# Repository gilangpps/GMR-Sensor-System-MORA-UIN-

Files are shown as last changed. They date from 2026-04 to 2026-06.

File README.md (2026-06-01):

# GMR Sensor System [MORA-UIN]

Real-time Giant Magnetoresistance sensor system for calibrated magnetic field measurement. Two kit variants, Python GUIs, MQTT IoT interface, and machine learning pipelines — built with Arduino + ADS1115.

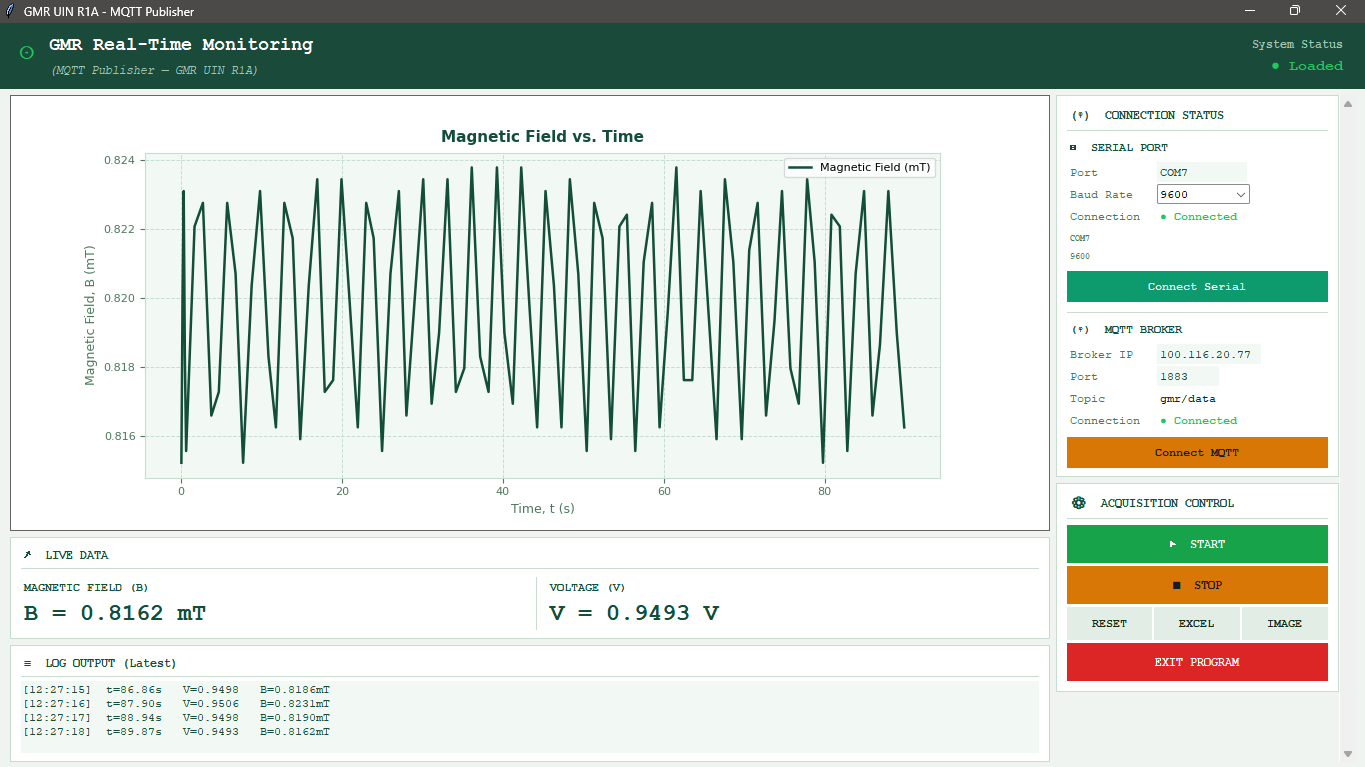
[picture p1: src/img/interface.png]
Interface Preview


---

## Hardware Variants

| Variant | Series | Color | Developed At |
|---|---|---|---|
| **GMR-UIN-R1A** | 1A | Blue | CV. Bolabot Techno Robotic Institute |
| **GMR-UIN-R1B** | 1B | Yellow | Lab. Fisika Material, UIN Bandung |

Identical in circuitry and firmware; differs only in series designation and enclosure color.

---

## Repository Structure

```
.
├── main.ino                         # Arduino firmware (ADS1115 reader)
├── magnetic_field_calibration.py    # Calibration script
├── output-template.xlsx             # Excel calibration template
│
├── GMR-UIN-R1A/                     # Blue kit
│   ├── GMR-UIN-R1A-Data-Acquisition.py
│   ├── src/                         # Calibration data, graphs
│   │   ├── r1a_calibration_report.xlsx
│   │   ├── r1a_calibration-graph.png
│   │   ├── r1a_regression-plot.png
│   │   ├── raw-data/                # (15 xlsx files, 1V–15V)
│   │   └── raw-b-data/              # (15 xlsx files, 1V–15V)
│   └── MQTT-interface/
│       ├── README.md
│       ├── 1.0.0/                   # Initial publisher & subscriber
│       ├── 1.0.0.f/                 # Feature-update patch
│       └── 1.1.0/                   # Latest patch
│
├── GMR-UIN-R1B/                     # Yellow kit
│   ├── GMR-UIN-R1B-Data-Acquisition.py
│   ├── src/
│   │   ├── r1b_calibration.png
│   │   ├── r1b_regression-plot.png
│   │   ├── r1b-calibration_report.xlsx
│   │   ├── raw_data/V_Helmholtz/    # (14 xlsx, 3V–16V)
│   │   └── raw-b-data/              # (13 xlsx, 3V–15V)
│   └── MQTT-interface/
│       ├── README.md
│       └── 1.1.0/                   # Publisher & subscriber
│
├── src/
│   ├── img/interface.png
│   ├── GMR-mechatronics.jpg
│   ├── manual-book-GMR-UIN-MORA.pdf
│   ├── schematic/                   # Schematics, PCB layout
│   └── docs/                        # Technical documentation
│
└── misc/
    ├── gui-prototype/               # 0.1.0 and 0.1.1 interface drafts
    └── machine-learning/
        ├── GMR_RF_glucose_monohydrate/          # RF regression (no GOx)
        ├── GMR_RF_GOx_Glucose Monohydrate/      # RF regression (with GOx)
        └── GMR_SVR-KNN-RF-Fe3O4/                # SVR / KNN / RF / LR models
```

---

## Quick Start

### 1. Arduino Firmware

Upload `main.ino` to your board. It reads the GMR sensor via ADS1115 (I²C) and outputs voltage over serial at 9600 baud.

### 2. Data Acquisition GUI

Pick your kit and run:

```bash
python GMR-UIN-R1A/GMR-UIN-R1A-Data-Acquisition.py   # Blue kit
python GMR-UIN-R1B/GMR-UIN-R1B-Data-Acquisition.py   # Yellow kit
```

### 3. Calibration

```bash
python magnetic_field_calibration.py
```

---

## MQTT Interface

Both kits support MQTT-based remote monitoring via publisher/subscriber modules. Multiple patch versions exist under each kit's `MQTT-interface/` directory. For Mosquitto broker setup and full documentation, refer to the respective `MQTT-interface/README.md`.

| Kit | Versions |
|-----|---|
| R1A | `1.0.0`, `1.0.0.f`, `1.1.0` |
| R1B | `1.1.0` |

---

## Machine Learning

Pre-trained models for Fe₃O₄ classification/regression and glucose concentration prediction (with/without GOx enzyme) are available under `misc/machine-learning/`.

---

## Environment Setup

**Dependencies:** `pyserial`, `matplotlib`, `pandas`, `openpyxl`, `paho-mqtt`

```bash
pip install pyserial matplotlib pandas openpyxl paho-mqtt
```

Adjust the serial port in the acquisition script (`COM3` / `/dev/ttyUSB0`) to match your system.

---

## Acknowledgements

Funded by **MORA The Air Funds 2025** — Ministry of Religious Affairs, Republic of Indonesia, in collaboration with LPDP, Ministry of Finance (Contract No. 68/Dt.I.III/PP.05/12/2024 and B-2594/Un.05/V.2/HM.01/12/2024), awarded to Universitas Islam Negeri Sunan Gunung Djati Bandung (2025–2027).

---

## License

Refer to the documentation in this repository or contact the development team for licensing information.

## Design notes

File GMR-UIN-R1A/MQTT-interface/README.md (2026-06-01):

# MQTT-based Giant Magnetoresistance Sensor System (GMR-UIN-R1A)

## Abstract

This project presents a comprehensive implementation of a distributed data acquisition and monitoring system for Giant Magnetoresistance (GMR) sensor measurements. The system leverages MQTT (Message Queuing Telemetry Transport) protocol to enable real-time data streaming, processing, and visualization across networked devices. The architecture comprises an embedded data acquisition unit, cloud-compatible publisher module, and flexible subscriber interface for remote monitoring and analysis.

---

## Table of Contents

1. [Introduction](#introduction)
2. [System Architecture](#system-architecture)
3. [Hardware Requirements](#hardware-requirements)
4. [Software Dependencies](#software-dependencies)
5. [Installation Guide](#installation-guide)
6. [System Configuration](#system-configuration)
7. [Operating Instructions](#operating-instructions)
8. [Calibration Procedures](#calibration-procedures)
9. [Troubleshooting](#troubleshooting)
10. [Directory Structure](#directory-structure)
11. [License](#license)

---

## Introduction

The MQTT GMR Sensor System is designed for real-time acquisition, processing, and remote monitoring of magnetic field measurements using Giant Magnetoresistance sensors. This system integrates:

- **Embedded Data Acquisition Unit**: Arduino-based controller interfacing with ADS1115 analog-to-digital converter
- **Publisher Module**: Python application for serial communication and MQTT data dissemination
- **Subscriber Module**: Real-time visualization and monitoring interface with graphical data representation
- **Network Communication**: MQTT broker-based distributed architecture supporting multiple client connections

### Key Features

- Real-time data acquisition at configurable sampling rates
- MQTT-based publisher-subscriber messaging paradigm
- Graphical user interface for interactive monitoring
- Data logging and export capabilities (CSV format)
- Calibrated magnetic field conversion from raw sensor voltages
- Multi-threaded architecture for non-blocking I/O operations
- Support for dual operational modes: Full-featured and Light modes

---

## System Architecture

### Component Overview

```
┌─────────────────────────────────────────────────────────────────┐
│                    MQTT-GMR Sensor System                        │
├─────────────────────────────────────────────────────────────────┤
│                                                                   │
│  ┌──────────────────┐         ┌──────────────────────────────┐   │
│  │   Arduino Unit   │         │   MQTT Broker               │   │
│  │  + ADS1115 ADC   ├────────►├─  (Network accessible)      │   │
│  │  + GMR Sensor    │         │                             │   │
│  └──────────────────┘         └──────────────────────────────┘   │
│         ▲                               ▲                         │
│         │ Serial                        │ MQTT                   │
│         │ (COM7, 9600 baud)            │ (Port 1883)            │
│         │                               │                         │
│  ┌──────┴───────────────────┐  ┌──────┴──────────────────────┐  │
│  │   Publisher Module       │  │  Subscriber Module          │  │
│  │  (Full/Light versions)   │  │  (Full/Light versions)      │  │
│  │                          │  │                             │  │
│  │ • Serial Reading         │  │ • Real-time Graphing        │  │
│  │ • Calibration            │  │ • Data Visualization        │  │
│  │ • MQTT Publishing        │  │ • CSV Export                │  │
│  │ • Visualization          │  │ • Status Monitoring         │  │
│  └──────────────────────────┘  └─────────────────────────────┘  │
│                                                                   │
└─────────────────────────────────────────────────────────────────┘
```

### MQTT Topics

| Topic | Publisher | Subscriber | Description |
|---|---|---|---|
| `gmr/data` | Publisher | Subscriber | Sensor data (voltage, B-field, timestamp) |
| `gmr/status` | Publisher | Subscriber | System status and connectivity information |

---

## Hardware Requirements

### Microcontroller Unit

- **Arduino Board**: Arduino Uno, Mega, or compatible microcontroller with I²C interface
- **Analog-to-Digital Converter**: Adafruit ADS1115 (16-bit, I²C protocol)
- **Sensor**: Giant Magnetoresistance (GMR) sensor with appropriate signal conditioning
- **Communication**: USB/Serial adapter for PC connectivity
- **Power Supply**: 5V regulated power supply

### Computing Platform

- **Processor**: Intel/AMD x86-64 processor (minimum 1 GHz)
- **Memory**: Minimum 2 GB RAM
- **Operating System**: Windows 10/11, Linux, or macOS
- **Network**: Ethernet or WiFi interface for MQTT broker connectivity
- **USB Interface**: USB 2.0 or higher for serial communication

### Network Infrastructure

- **MQTT Broker**: Mosquitto, EMQ, or compatible MQTT server
- **Network**: TCP/IP LAN or WAN connectivity
- **Port Configuration**: MQTT default port 1883 (or alternative as configured)

---

## Software Dependencies

### Python Runtime

- **Python Version**: 3.8 or higher
- **Package Manager**: pip (Python Package Installer)

### Required Python Packages

| Package | Version | Purpose |
|---|---|---|
| `paho-mqtt` | ≥2.0.0 | MQTT client library for Python |
| `pyserial` | ≥3.5 | Serial port communication |
| `matplotlib` | ≥3.5.0 | Data visualization and real-time plotting |
| `pandas` | ≥1.3.0 | Data manipulation and CSV export |
| `tkinter` | Built-in | Graphical User Interface framework |

### Arduino Libraries

- **Wire.h**: I²C communication (standard Arduino library)
- **Adafruit_ADS1X15**: ADS1115 driver library
  - Installation: Via Arduino IDE Library Manager or manual download

### System Requirements

- **Serial Driver**: CH340 or FTDI driver (depending on USB adapter)
- **MQTT Broker**: Accessible network location with port 1883 open

---

## Installation Guide

### Step 1: Python Environment Setup

#### Option A: Using Virtual Environment (Recommended)

```bash
# Navigate to project directory
cd path/to/MQTT-GMR-1A

# Create virtual environment
python -m venv gmr_env

# Activate virtual environment
# On Windows:
gmr_env\Scripts\activate
# On Linux/macOS:
source gmr_env/bin/activate
```

#### Option B: Direct Installation

Skip the virtual environment if preferred (not recommended for production).

### Step 2: Install Python Dependencies

```bash
# Install required packages from the dependency manifest
pip install -r requirements.txt

# Verify installation
pip list
```

### Step 3: Arduino Board Setup

1. **Install Arduino IDE** from official Arduino website (https://www.arduino.cc/en/software)

2. **Install Board Support** (if using non-standard board):
   - Open Arduino IDE → Preferences
   - Add board manager URL if needed
   - Tools → Board Manager → Install appropriate board

3. **Install Required Libraries**:
   - Sketch → Include Library → Manage Libraries
   - Search for "Adafruit ADS1X15"
   - Install latest version

4. **Connect Arduino Board**:
   - Connect via USB cable
   - Tools → Board → Select appropriate board
   - Tools → Port → Select corresponding COM port
   - Tools → Serial Monitor → Verify communication at 9600 baud

### Step 4: Upload Arduino Firmware

1. Open `/main/main.ino` in Arduino IDE
2. Configure settings:
   ```cpp
   #define BAUDRATE 9600        // Serial communication speed
   #define ADS_GAIN GAIN_TWO    // ADC gain setting (±2.048V)
   ```
3. Verify code: Sketch → Verify/Compile
4. Upload: Sketch → Upload
5. Monitor serial output: Tools → Serial Monitor

### Step 5: MQTT Broker Installation

#### Option A: Local Installation (Windows)

1. Download Mosquitto from https://mosquitto.org/download/
2. Install with default settings
3. Default configuration: Localhost, port 1883
4. Verify broker running: Command Prompt → `mosquitto -v`

#### Option B: Remote Broker

Configure broker IP address in Python scripts:
```python
MQTT_BROKER = '192.168.1.100'  # Replace with broker IP
```

---

## System Configuration

### Publisher Configuration

Edit `GMR-UIN-R1A-Publisher.py`:

```python
# Serial Configuration
SERIAL_PORT  = 'COM7'          # Adjust to your Arduino port
BAUD_RATE    = 9600            # Must match Arduino configuration

# MQTT Configuration
MQTT_BROKER  = '100.116.20.77' # Broker IP address
MQTT_PORT    = 1883            # Default MQTT port
MQTT_TOPIC_DATA  = 'gmr/data'
MQTT_TOPIC_STATUS = 'gmr/status'
MQTT_CLIENT_ID   = 'GMR-Publisher'

# Calibration Parameters
def tegangan_ke_b(v):
    return 5.3381 * v - 4.2983  # Voltage to Magnetic Field conversion
```

### Subscriber Configuration

Edit `GMR-UIN-R1A-Subscriber.py`:

```python
# MQTT Configuration
MQTT_BROKER      = 'localhost'  # Broker IP address
MQTT_PORT        = 1883
MQTT_TOPIC_DATA  = 'gmr/data'
MQTT_TOPIC_STATUS = 'gmr/status'
MQTT_CLIENT_ID   = 'GMR-Subscriber'
```

### Identify Serial Port

**Windows**:
```bash
# List COM ports
mode

# Or in Python:
import serial.tools.list_ports
ports = serial.tools.list_ports.comports()
for p in ports:
    print(p)
```

**Linux/macOS**:
```bash
ls /dev/tty*
```

---

## Operating Instructions

### Launch Publisher Module

```bash
# Activate virtual environment (if used)
gmr_env\Scripts\activate  # Windows
source gmr_env/bin/activate  # Linux/macOS

# Run publisher
python GMR-UIN-R1A-Publisher.py
```

### Launch Subscriber Module

In a separate terminal:

```bash
# Activate virtual environment
gmr_env\Scripts\activate  # Windows

# Run subscriber
python GMR-UIN-R1A-Subscriber.py
```

### Publisher GUI Operations

1. **Connect Arduino**: Click "Hubungkan Serial" (Connect Serial)
2. **Start Data Collection**: Click "Mulai Pengumpulan Data" (Start Collection)
3. **Monitor MQTT Status**: Observe connection indicator
4. **Export Data**: File → Export CSV to save measurements
5. **View Real-time Plot**: Graph updates automatically during collection

### Publisher GUI Preview

Publisher GUI

### Subscriber GUI Operations

1. **Connection Status**: Green indicator when connected to MQTT broker
2. **Real-time Plot**: Displays magnetic field (B) vs. time
3. **Data Table**: Shows latest measurements
4. **Export Function**: Save monitored data as CSV
5. **Publisher Status**: Displays connected/disconnected status

### Subscriber GUI Preview

Subscriber GUI

### Light Mode Operation

For simplified, resource-efficient operation:

```bash
python light-mode/Light-Publisher.py
python light-mode/Light-Subscriber.py
```

---

## Calibration Procedures

### Magnetic Field Conversion

The system converts raw voltage measurements to magnetic field values using a linear calibration formula:

$$B = a \cdot V + b$$

Where:
- $B$ = Magnetic field (unit: Tesla or mT, as calibrated)
- $V$ = Sensor voltage (Volts)
- $a$ = Slope coefficient (default: 5.3381)
- $b$ = Intercept coefficient (default: -4.2983)

### Calibration Steps

1. **Obtain Reference Standards**: Use calibrated magnetic field sources (e.g., Helmholtz coil)

2. **Collect Reference Data**:
   - Apply known magnetic field strengths
   - Record corresponding sensor voltages
   - Generate minimum 5 data points covering measurement range

3. **Calculate Coefficients**:
   ```python
   import numpy as np
   
   # Reference data
   voltages = [0.8, 1.2, 1.6, 2.0, 2.4]  # Volts
   fields = [0.0, 2.5, 5.0, 7.5, 10.0]    # mT
   
   # Linear regression
   coeffs = np.polyfit(voltages, fields, 1)
   a = coeffs[0]  # Slope
   b = coeffs[1]  # Intercept
   ```

4. **Update Calibration**:
   ```python
   def tegangan_ke_b(v):
       return a * v + b  # Replace 'a' and 'b' with calculated values
   ```

5. **Validate**: Re-measure reference standards and verify accuracy

---

## Troubleshooting

### Serial Communication Issues

**Problem**: "Serial port not found" or "Port already in use"

**Solutions**:
- Verify Arduino connection: Check Device Manager (Windows) or `ls /dev/tty*` (Linux)
- Confirm correct COM port in configuration
- Ensure serial driver installed (CH340 or FTDI)
- Close other serial monitor applications
- Restart Arduino board

**Problem**: Garbled data or no data from serial

**Solutions**:
- Verify baud rate matches Arduino configuration (must be 9600)
- Check USB cable quality and connection
- Test with Arduino IDE Serial Monitor at 9600 baud
- Recompile and re-upload Arduino firmware

### MQTT Connection Issues

**Problem**: "Connection refused" or "Unable to connect to broker"

**Solutions**:
- Verify MQTT broker IP address in configuration
- Check broker is running: `mosquitto -v` (command line test)
- Verify network connectivity: `ping <broker_ip>`
- Check firewall allows port 1883
- Verify MQTT port matches configuration (default: 1883)

**Problem**: "No messages received" in Subscriber

**Solutions**:
- Confirm Publisher connected successfully (check status indicator)
- Verify MQTT topics match between Publisher and Subscriber
- Check MQTT broker is receiving messages:
  ```bash
  mosquitto_sub -h <broker_ip> -t "gmr/data"
  ```
- Restart both Publisher and Subscriber applications

### GUI/Display Issues

**Problem**: Graphs not updating or freezing interface

**Solutions**:
- Ensure matplotlib properly installed: `pip install --upgrade matplotlib`
- Check system resources (RAM, CPU usage)
- Reduce data collection rate
- Restart application

**Problem**: CSV export fails

**Solutions**:
- Verify write permissions in target directory
- Check available disk space
- Ensure pandas library installed: `pip install --upgrade pandas`

### Python Runtime Issues

**Problem**: Module import errors (e.g., "No module named 'paho'")

**Solutions**:
- Verify virtual environment activated
- Reinstall dependencies: `pip install -r requirements.txt`
- Check Python version: `python --version` (must be 3.8+)

---

## Directory Structure

```
MQTT-GMR-Sensor-System-UIN-R1A-/
├── README.md                      # This file
├── requirements.txt               # Python dependencies
├── main/
│   └── main.ino                   # Arduino firmware (ADS1115 interface)
├── patch1-0-0/
│   ├── dark-mode/
│   │   ├── GMR-UIN-R1A-Publisher.py      # Full-featured publisher module
│   │   └── GMR-UIN-R1A-Subscriber.py     # Full-featured subscriber module
│   └── light-mode/
│       ├── Light-Publisher.py            # Simplified publisher (low resource)
│       └── Light-Subscriber.py           # Simplified subscriber (low resource)
├── patch1-1/
│   ├── 1_GMR-UIN-R1A-Publisher.py        # Updated publisher module
│   └── 1_GMR-UIN-R1A-Subscriber.py       # Updated subscriber module
└── src/
    ├── publisher-GUI.png                 # Publisher GUI preview
    └── subscriber-GUI.png                # Subscriber GUI preview
```

### File Descriptions

| File | Purpose | Platform |
|---|---|---|
| `main/main.ino` | Arduino firmware for ADS1115 sensor reading | Arduino IDE |
| `patch1-0-0/dark-mode/GMR-UIN-R1A-Publisher.py` | Serial acquisition, MQTT publishing, GUI | Python (Windows/Linux/macOS) |
| `patch1-0-0/dark-mode/GMR-UIN-R1A-Subscriber.py` | MQTT subscription, real-time visualization | Python (Windows/Linux/macOS) |
| `patch1-0-0/light-mode/Light-Publisher.py` | Resource-optimized publisher variant | Python |
| `patch1-0-0/light-mode/Light-Subscriber.py` | Resource-optimized subscriber variant | Python |
| `patch1-1/1_GMR-UIN-R1A-Publisher.py` | Updated publisher module | Python |
| `patch1-1/1_GMR-UIN-R1A-Subscriber.py` | Updated subscriber module | Python |
| `src/publisher-GUI.png` | Screenshot of publisher GUI interface | Image |
| `src/subscriber-GUI.png` | Screenshot of subscriber GUI interface | Image |

---

## Contact & Support

For technical inquiries or contributions, please contact the project maintainers:

**Institution**: Universitas Islam Negeri Sunan Gunung Djati Bandung
**Department**: [Jurusan Fisika, Fakultas Sains dan Teknologi, UIN Sunan Gunung Djati Bandung]
**Last Updated**: May 8, 2026

---

## Citation

If you utilize this system in your research, please cite as follows:

```bibtex
@software{gmr_mqtt_2026,
  title   = {MQTT-based Giant Magnetoresistance Sensor System (GMR-UIN-R1A)},
  author  = {G8lang Pratama Putra Siswanto},
  year    = {2026},
  url     = {https://github.com/gilangpps/MQTT-GMR-Sensor-System-UIN-R1A-.git},
  organization = {Bex 7386 Mini-Techlab}
}
```

---

**Document Version**: 1.0
**Last Modified**: May 8, 2026

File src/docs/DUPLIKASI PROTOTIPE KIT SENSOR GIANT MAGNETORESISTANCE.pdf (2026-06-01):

DUPLIKASI PROTOTIPE KIT SENSOR GIANT

MAGNETORESISTANCE (GMR)

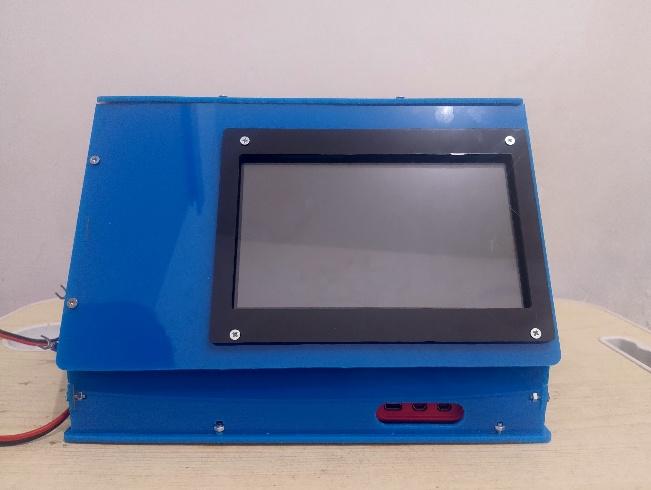
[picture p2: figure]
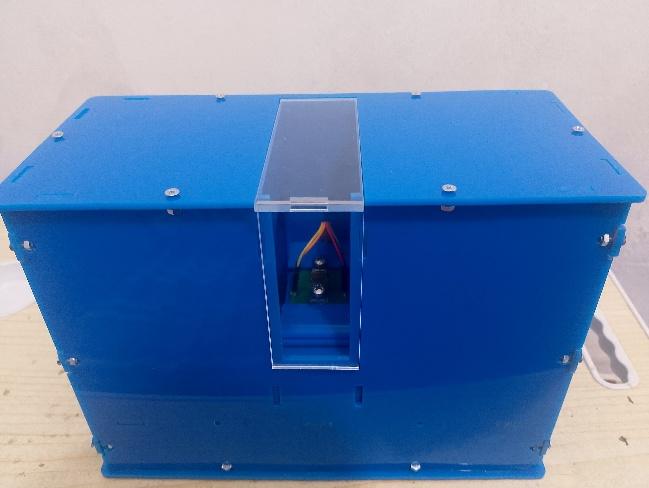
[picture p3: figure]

Replikasi prototipe kit sensor Giant Magnetoresistance AAL024 diaplikasikan dari

analisis menyeluruh terhadap konfigurasi dan spesifikasi kit yang telah ada, termasuk

komponen utama seperti unit mikrokontroler, sistem penguat sinyal, kumparan penghasil

medan referensi, serta antarmuka perangkat lunak yang menampilkan hasil pengukuran.

Panduan penggunaan kit yang menjadi acuan menyajikan detail mengenai susunan perangkat,

spesifikasi sensor, rentang pengukuran, dan prosedur uji dasar yang dipakai pada prototipe

awal, sehingga dokumentasi itu menjadi titik tolak dalam proses duplikasi.

Komponen sistem sensor direplikasi mencakup kumparan Helmholtz yang disusun

dengan diameter 9 cm, jarak antar kumparan 4.5 cm, jumlah lilitan 300 putaran menggunakan

kawat tembaga berdiameter 0.5 mm, dan resistansi 0.9 Ohm berdaya 10 Watt. Dengan

konfigurasi ini, medan magnet yang dihasilkan tetap berada pada rentang 0,04 hingga 1,5

miliTesla sehingga setiap unit memiliki kemampuan stimulasi medan yang seragam.

Mikrokontroler Arduino Uno R3 tetap berfungsi sebagai pengendali utama untuk pembacaan

transduser GMR tipe AAL024. Tahap pengolahan sinyal direplikasi dengan struktur yang sama

seperti prototipe, dengan menggunakan op-amp LM358 yang menyediakan penguatan sekitar

47 kali pada jalur non-inverting dan 21 kali pada jalur inverting. Nilai penguatan ini

memastikan sinyal jembatan dari sensor tetap berada dalam rentang yang sesuai untuk proses

digitalisasi. Sistem filtrasi menggunakan filter pasif low band-pass dengan frekuensi cutoff

39.8 Hertz sehingga sinyal yang masuk ke ADC terbebas dari gangguan frekuensi tinggi.

Proses digitasi data mengaplikasikan ADC ADS1115 dengan resolusi 16-bit melalui jalur komunikasi I²C. Hubungan data antara ADC, Arduino, dan Raspberry Pi tetap menggunakan

struktur prototipe agar alur akuisisi hingga visualisasi tidak mengalami deviasi.

Data diambil berulang kali untuk memperoleh metrik statistik seperti rerata, deviasi

standar, dan koefisien variasi antar unit. Indikator kinerja utama (key performance indicators)

mencakup reproducibility yang diharapkan pada kisaran koefisien variasi rendah, rasio signal

to noise yang memadai setelah filtering dan averaging, serta drift sinyal yang minimal selama

kondisi beban dan variasi temperatur terkontrol. Semua hasil uji, nilai kalibrasi, dan versi

firmware dicatat untuk analisis tren dan koreksi sumber variasi seperti toleransi komponen atau

proses solder. Dengan konfigurasi fisik dan parameter sinyal yang dipertahankan, kit GMR

AAL024 menunjukkan kecocokan untuk aplikasi deteksi magnetik pada skala nano dan

biosensing berbasis label magnetik asalkan praktik pengukuran dan persiapan sampel

disesuaikan. Sensitivitas sensor dan konfigurasi penguat memungkinkan deteksi perubahan

medan pada orde mikroTesla hingga miliTesla sehingga deteksi nanopartikel magnetik,

nanofiber bermuatan magnetik, ataupun nanokomposit magnetik dapat dilakukan ketika

densitas partikel dan geometri sampel mendukung sinyal yang melebihi ambang kebisingan.

Untuk aplikasi biosensor bermagnetik, validitas hasil bergantung pada efisiensi pelabelan

magnetik, kontrol nonspesifik, pengaturan jarak sensor ke sampel, serta penggunaan shielding

dan averaging sinyal untuk meningkatkan rasio sinyal terhadap kebisingan. Dengan protokol

kalibrasi, pengendalian kualitas, dan dokumentasi yang konsisten, replikasi prototipe tidak

hanya memungkinkan pelatihan dan produksi massal tetapi juga membangun keandalan deteksi

untuk aplikasi nanopartikel dan biosensor berbasis magnetik.

Keseluruhan proses duplikasi menghasilkan kit yang tidak hanya meniru bentuk fisik

tetapi juga seluruh nilai operasional, mulai dari catu daya, penguatan sinyal, filtrasi,

pencuplikan digital, hingga pemrosesan pada mikrokomputer. Identitas teknis yang dijaga

secara ketat memungkinkan evaluasi konsistensi performa antar unit, sekaligus mempersiapkan

sistem untuk proses pelatihan produksi massal.

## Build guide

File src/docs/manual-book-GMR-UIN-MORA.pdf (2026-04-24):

## PANDUAN PENGGUNAAN KIT SENSOR GIANT

## MAGNETORESISTANCE (GMR) AAL024

Disusun Oleh:

Tim Riset Instrumentasi GMR

TIM RISET INSTRUMENTASI GMR

TAHUN 2025

## SENSOR GIANT MAGNETORESISTANCE (GMR)

Sensor Giant Magnetoresistance (GMR) merupakan perangkat transduser magnetik yang

memanfaatkan fenomena kuantum berupa perubahan signifikan pada resistansi listrik material

ketika terkena medan magnet eksternal. Efek GMR pertama kali ditemukan pada tahun 1988

oleh Albert Fert dan Peter Grünberg dalam struktur multilayer yang terdiri dari lapisan

feromagnetik (seperti besi atau kobalt) dan lapisan non-magnetik (seperti kromium atau

tembaga) yang disusun secara bergantian pada ketebalan nanometer (Fert, 1988; Grünberg et

al., 1989). Temuan ini meraih Nobel Fisika 2007 karena mendasari pengembangan spintronics,

bidang yang memanfaatkan spin elektron selain muatannya untuk pemrosesan informasi

(Nobel Foundation, 2007).

Prinsip kerja sensor GMR berakar pada hamburan elektron tergantung spin (spin-

dependent scattering) dalam struktur material. Dalam material feromagnetik, resistansi listrik

bergantung pada orientasi relatif antara spin elektron dan magnetisasi material. Elektron

dengan spin sejajar dengan magnetisasi (spin mayoritas) mengalami hamburan lebih sedikit

dan memiliki jalur bebas rata-rata (mean free path) lebih panjang, sementara elektron dengan

spin antiparalel (spin minoritas) mengalami hamburan lebih intensif. Dalam konfigurasi spin-

valve, resistansi total sistem ditentukan oleh orientasi relatif magnetisasi lapisan referensi dan

lapisan bebas:

- Magnetisasi paralel: Resistansi rendah karena elektron mayoritas melewati kedua

lapisan dengan sedikit hamburan.

- Magnetisasi antiparalel: Resistansi tinggi karena elektron mayoritas di lapisan

pertama menjadi minoritas di lapisan kedua sehingga lebih banyak dihamburkan610.

Secara | matematis, | resistansi | dinyatakan | sebagai:
| | R = Rmin + (ΔR)
| | 2

(1 − cosθ)

di mana θ adalah sudut relatif antara magnetisasi lapisan bebas dan referensi, Rmin

adalah resistansi minimum saat θ = 0 (paralel), dan ΔR adalah perubahan resistansi

maksimum.

## PENDAHULUAN KIT SENSOR

Kit sensor GMR AAL024 terdiri dari beberapa blok komponen utama, yaitu bagian

mikrokoprosesor Raspberry Pi 5 8GB RAM dengan layer monitor 7 inci, catu daya eksternal,

serta instrumen sensor GMR AAL024 terintegrasi dengan mikrokontroler Arduino Uno R3.

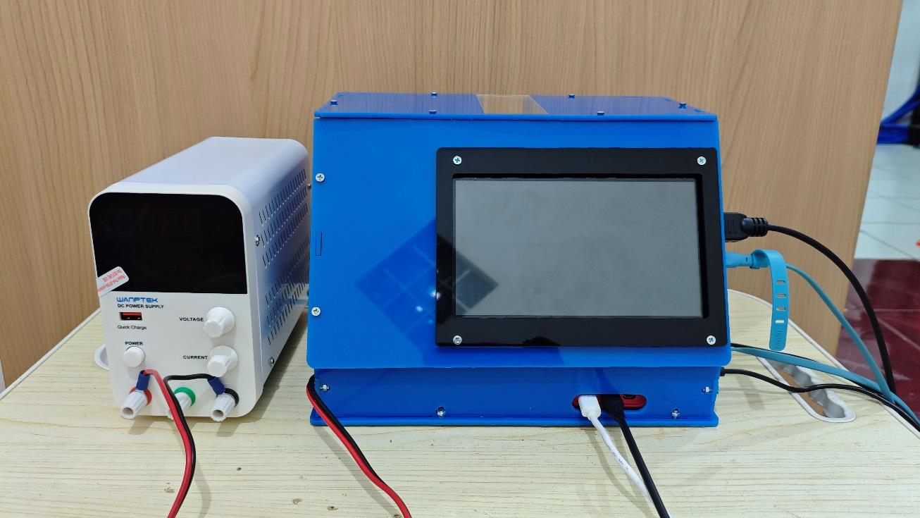
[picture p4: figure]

Gambar 1 - Tampilan Kit Sensor GMR AAL024

## SPESIFIKASI UTAMA

Kit sensor GMR AAL024 menunjang penggunaan transduser sensitif terhadap

perubahan medan magnet dengan detail spesifikasi sebagai berikut.

CATU DAYA EKSTERNAL

Tabel 1 - Spesifikasi Catu Daya Eksternal Kit Sensor GMR

Tegangan Masukan | AC 115V/230V
Tegangan Keluaran | DC 0~30V
Arus Keluaran | DC 0~5A
Daya Keluaran | 150W
Spesifikasi Sekering | 3A

MIKROKOMPUTER

Tabel 2 - Spesifikasi Mikrokomputer Kit Sensor GMR

Jenis Mikroprosesor | Raspberry Pi 5
Spesifikasi Prosesor | Broadcom BCM2712 2.4GHz quad-core 64-bit Arm Cortex-A76 CPU
RAM | LPDDR4X-4267 SDRAM 8GB
Jenis Penyimpanan | Eksternal (kartu microSD)
Spesifikasi Layar | 7 inci layer sentuh, tegangan kerja 5V DC menggunakan port USB, kabel transmisi berbasis HDMI
Catu daya utama | DC 5V/5A kabel daya tipe-C
Kontrol | Eksternal (keyboard dan mouse)
Ports | 2 x USB 3.0 ports 2 x USB 2.0 ports 2 x Micro USB ports 1 x Type-C port

SISTEM TERINTEGRASI SENSOR GMR

Tabel 3 - Spesifikasi Sistem Terintegrasi Sensor Kit Sensor GMR

Jenis Medan Magnet Eksternal | Kumparan Helmholtz
Spesifikasi Kumparan | -Diameter kumparan: 9cm - Jarak antarkumparan: 4,5cm - Jumlah lilitan: 300 lilitan - Jenis kawat: kawat tembaga 0,5mm - Resistansi: 10 Ohm 50W
Rentang Medan Magnet | 0,04~1,5mT
Jenis Mikrokontroler | Arduino Uno R3
Jenis Transduser | Sensor Giant Magnetoresistance (GMR)
Tipe Sensor | AAL024 GMR Sensor

Spesifikasi sensor | - | Polaritas | Magnetik: | Omnipolar

(dapat mendeteksi kedua kutub

magnet).

- Rentang Pengukuran Medan Magnet:

0,15 hingga 1,05 mT.

- Rentang Pengukuran Arus: 1 hingga

10 A.

- Sensitivitas: 36 mV/V/mT.
- Output: Sinyal keluaran berupa

jembatan (bridge).

- | Medan | Minimum | yang | Dapat

Dideteksi: 10 µT.

- | Arah | Sensitivitas: | Cross-axis

(sensitif terhadap medan melintang).

- Tegangan Suplai: 0 hingga 12 V.
- Resistansi Jembatan: 2,2 kΩ.
- Mode Penginderaan Arus: Over-
trace | (melacak | arus | di | atas

konduktor).

- Suhu Maksimum yang Didukung:

125°C.

Jenis Penguatan | Operational Amplifier Subtractor LM358
Nilai Penguatan Sinyal | 47x untuk masukan non-inverting 21x untuk masukan inverting
Jenis Filtrasi | Filter pasif Low Band-pass
Nilai Frekuensi Cutoff | 40 Hz
Pemrosesan sinyal | Analog to Digital Converter (ADC)
Tipe ADC | ADS1115 16-bit ADC
Antarmuka transmisi data | Inter-integrated Circuit (I²C)

## SKEMA MEKATRONIKA KIT SENSOR GMR

Bagian ini akan menampilkan panduan skema mekatronika kit sensor GMR beserta

keterangan setiap bagiannya.

Tabel 4 – Skema Mekatronika Kit Sensor GMR

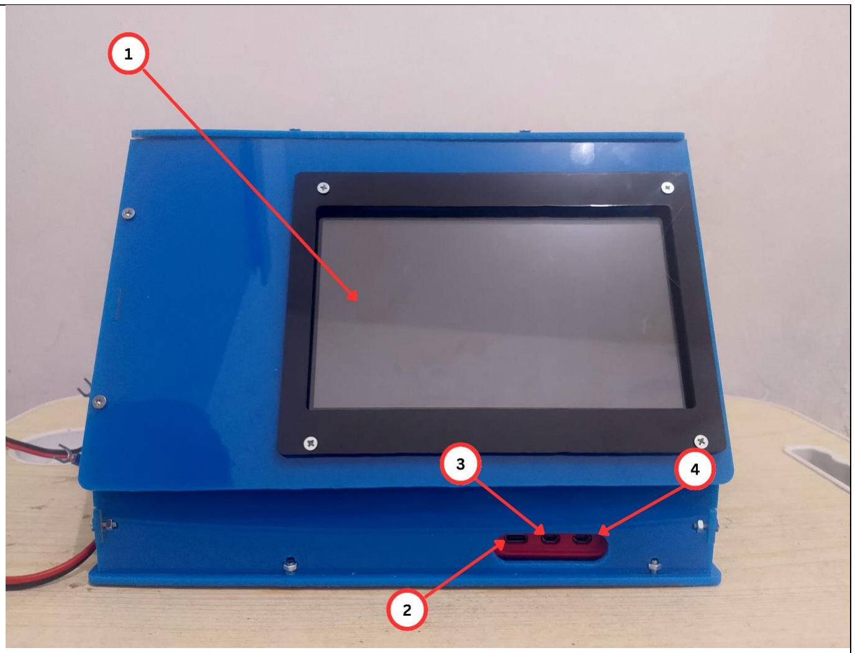
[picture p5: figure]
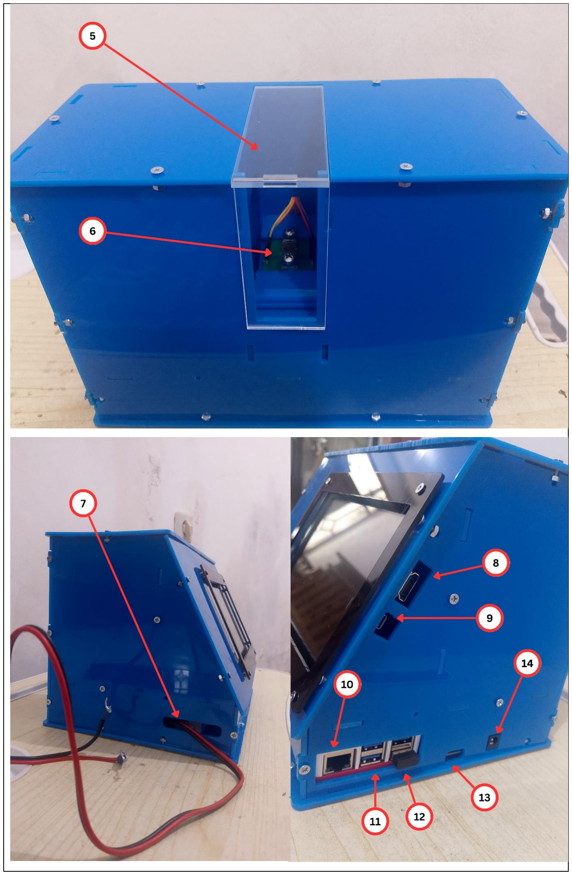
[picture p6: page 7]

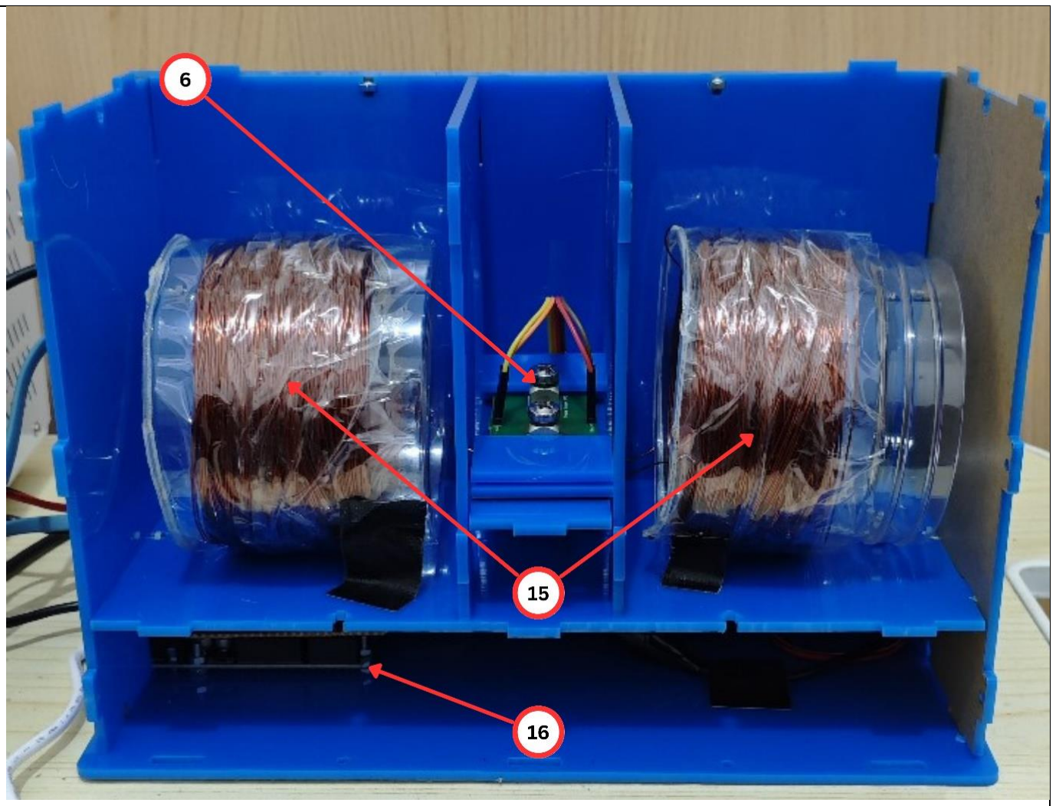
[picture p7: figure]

Keterangan:

1. Layar monitor 7 Inci
2. Port tipe-C
3. Port micro USB
4. Port micro USB
5. Penutup ruang uji kit
6. Sensor GMR AAL024
7. Skun konektor catu daya
8. Port HDMI layar
9. Port micro USB layar
10. Port Ethernet (RJ45)
11. Port 2 x USB 3.0
12. Port 2 x USB 2.0
13. Port tipe-C Arduino Uno
14. DC port Arduino Uno
15. Kumparan Helmholtz
16. Sistem sensor terintegrasi Arduino Uno

## PROSEDUR PENGGUNAAN

Penggunaan kit sensor GMR mencakup beberapa tahapan utama yaitu setup kit secara

keseluruhan dan penyambungan terhadap catu daya, pengoperasian sistem pada

mikrokomputer untuk uji kit, dan prosedur pengujian kit dalam deteksi sampel beserta tahapan

pemeliharaan dan keamanan kit sensor.

INISIALISASI KIT

Tahapan ini mencakup setup rangkaian dengan menghubungkan kabel konektor untuk

menyuplai daya pada kit secara keseluruhan. Tahapan yang ditempuh adalah sebagai berikut.

1. Hubungkan skun konektor catu daya pada kit sensor terhadap catu daya eksternal DC.
2. Hubungkan kabel micro USB to HDMI pada HDMI monitor terhadap port micro USB

mikrokomputer.

3. Hubungkan kabel USB to micro USB pada port USB 2.0 mikrokomputer terhadap port

micro USB monitor. Kedua kabel ini memastikan saluran daya dan transmisi grafis

memadai untuk menampilkan konten dari mikrokomputer.

4. Hubungkan kabel USB to type-C pada port USB 3.0 mikrokomputer terhadap port tipe-

C Arduino Uno untuk suplai daya sekaligus pembacaaan data dari sistem sensor

terhadap mikrokomputer.

5. Hubungkan catu daya 5V/5A tipe-C terhadap port tipe-C mikrokomputer untuk

menyuplai daya mikrokomputer. Sistem kit akan otomatis bekerja ditandai dengan layar

monitor yang menampilkan konten.

6. Untuk keperluan masukan kontrol pada mikrokomputer, dapat diaplikasikan mouse

atau keyboard pada port USB yang tersedia.

PROSEDUR PENGOPERASIAN SISTEM KIT UNTUK UJI SENSOR

Sistem kit yang telah diinisialisasi dengan baik siap untuk digunakan dalam

pengoperasian sistem untuk uji sensor. Tahapan yang ditempuh adalah sebagai berikut.

1. Nyalakan catu daya kemudian atur nilai tegangan dan arus yang hendak diaplikasikan

pada sistem kit.

2. Pada tampilan layar utama, akan muncul desktop utama dari sistem kit.

3. Buka piranti lunak Thonny IDE interpreter untuk mengoperasikan program berbasis

bahasa Python dalam tahapan uji sensor. Kode program utama untuk menjalankan

sistem sensor disajikan pada tautan sebagai berikut.

Tautan Kode Program Python Uji Sensor:

https://drive.google.com/file/d/1NskpXGHlsbha5DMSa6HUh825qOCeIs_Y/view?usp=sha

ring (https://drive.google.com/file/d/1NskpXGHlsbha5DMSa6HUh825qOCeIs_Y/view?usp=sharing)

4. Jalankan program dengan membuka berkas program, lalu menekan toolbar “run”.

Setelah ditekan, akan muncul jendela graphical user interface untuk program uji sensor

sebagai berikut.

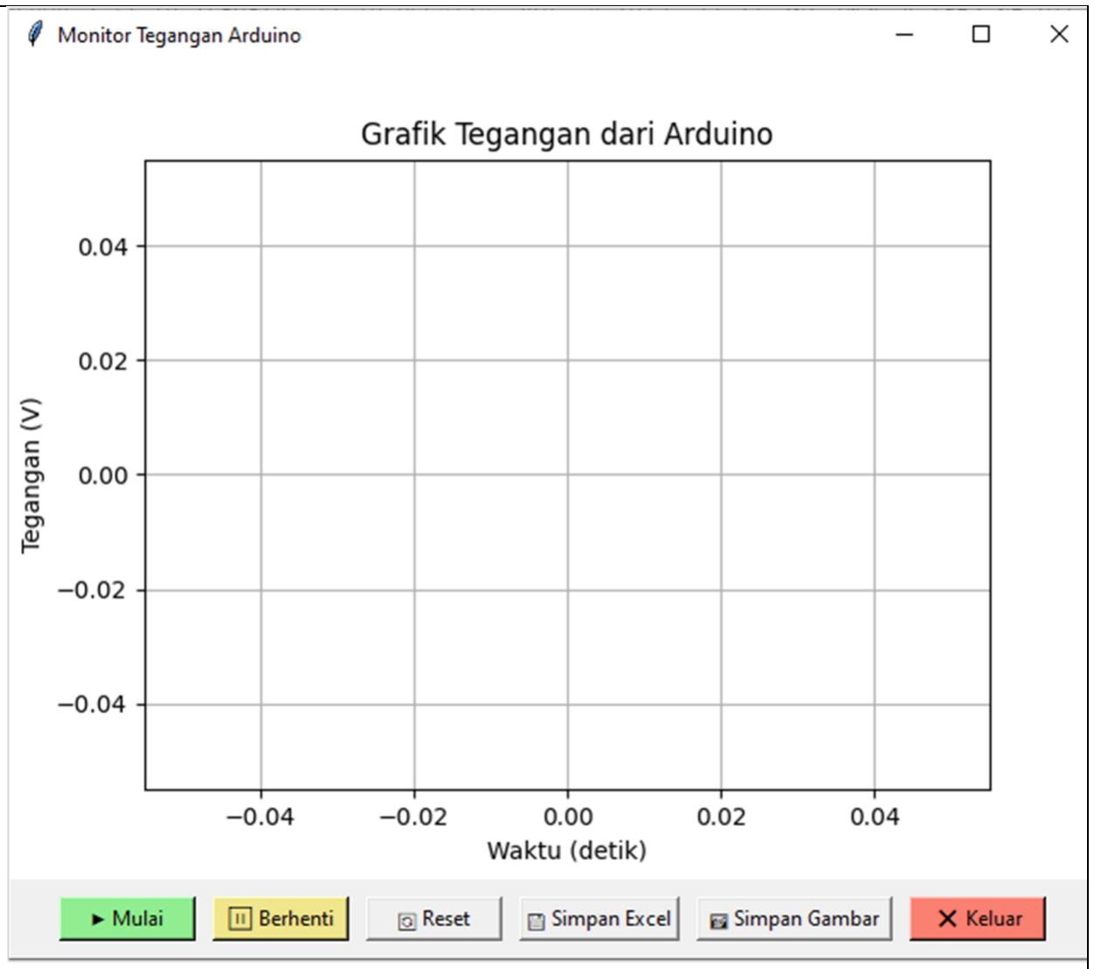
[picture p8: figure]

Gambar 3 – Jendela GUI Python untuk Sistem Uji Sensor GMR

5. Terdapat beberapa tombol utama, tombol “Mulai” untuk memulai proses akuisisi data

dari sensor, tombol “Berhenti” untuk menghentikan proses akuisisi data, tombol

“Reset” untuk mengulangi tahapan akuisisi data sensor, tombol “Simpan Excel” untuk

menyimpan data dalam format Excel, dan “Simpan Gambar” untuk menyimpan grafik

dalam format gambar png. Jika tahapan akuisisi data berhasil dijalankan, klik tombol

“Keluar” untuk menutup jendela GUI.

PROSEDUR UJI SAMPEL, PEMELIHARAAN DAN KEAMANAN

SENSOR

Prosedur menjelaskan terkait tahapan yang ditempuh untuk penggunaan kit sensor

dalam uji sampel, disertai tahapan pemeliharaan dan keamanan sensor.

1. Pada tampilan layar utama pada monitor, ditampilkan desktop utama dari sistem kit.
2. Buka piranti lunak Thonny IDE interpreter untuk mengoperasikan program berbasis

bahasa Python dalam tahapan uji sensor. Kode program utama untuk menjalankan

sistem sensor disajikan pada tautan sebagai berikut.

Tautan Kode Program Python Uji Sensor:

https://drive.google.com/file/d/1NskpXGHlsbha5DMSa6HUh825qOCeIs_Y/view?usp=sha

ring (https://drive.google.com/file/d/1NskpXGHlsbha5DMSa6HUh825qOCeIs_Y/view?usp=sharing)

3. Jalankan program dengan membuka berkas program, lalu menekan toolbar “run”.

Setelah ditekan, akan muncul jendela graphical user interface untuk program uji sensor

sebagai berikut.

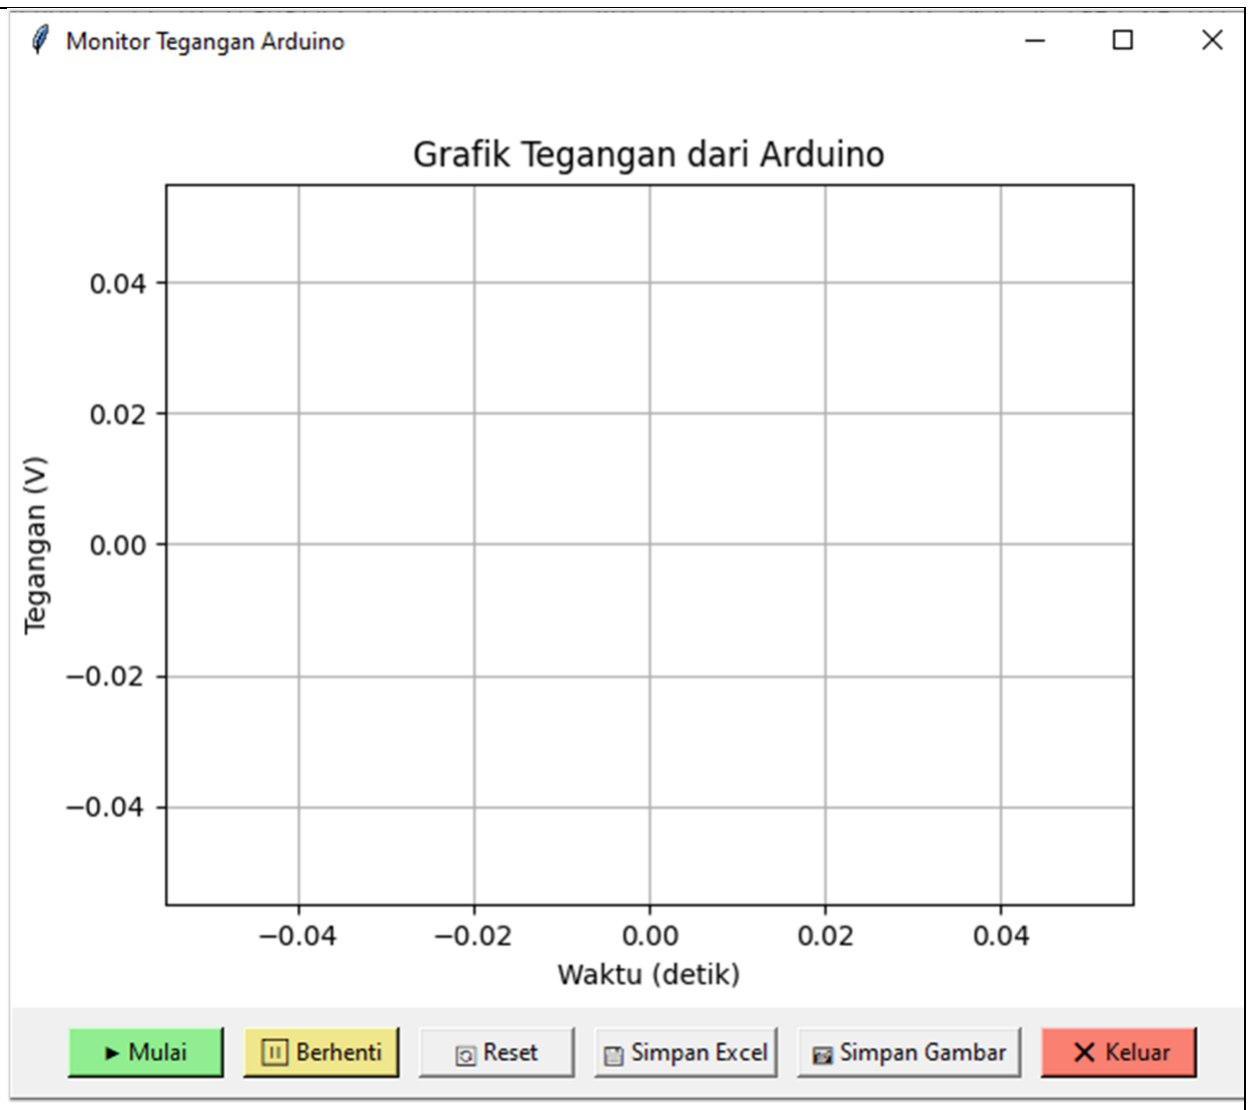
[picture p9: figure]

Gambar 4 – Jendela GUI Python untuk Sistem Uji Sensor GMR

4. Preparasi sampel yang telah disiapkan, alat untuk menuangkan sampel pada sensor

menggunakan mikropipet.

5. Buka penutup ruang uji kit sensor.
6. Tuangkan sampel yang hendak diuji di atas sensor.
7. Tunggu etanol pada sampel hingga mengalami tahapan evaporasi sehingga menyisakan

sampel uji. Estimasi waktu untuk etanol mengalami evaporasi adalah selama 5 menit.

8. Nyalakan catu daya kemudian atur nilai tegangan dan arus yang hendak diaplikasikan

pada sistem kit.

9. Klik tombol “Mulai” untuk memulai akuisisi data.
10. Klik tombol “Berhenti” untuk menghentikan proses akuisisi data atau “Reset” untuk

mengulangi proses akuisisi data.

11. Simpan data yang diperoleh menggunakan “Simpan Excel” untuk menyimpan data

dalam format Excel dan tombol “Simpan Gambar” untuk menyimpan grafik dalam

format gambar.

12. Matikan catu daya ketika proses uji sampel pada kit sensor berhasil dilakukan.
13. Bersihkan sensor yang telah digunakan menggunakan cotton buds yang dibasahi etanol.
14. Sensor siap digunakan kembali menggunakan sampel selanjutnya.

Prosedur Keamanan:

Kumparan Helmholtz menyalurkan energi dengan voltase dan arus bervariasi sesuai

keluaran catu daya. Tegangan dan arus yang kontinu menyebabkan disipasi panas pada

kumparan yang berimplikasi pada stabilitas pembacaan sensor yang menurun.

Disarankan untuk memberikan jeda di antara setiap uji variasi sampel dengan membatasi

pengujian hingga ~30 menit, diiringi proses mematikan catu daya hingga suhu kumparan

menurun (estimasi selama 15 menit).

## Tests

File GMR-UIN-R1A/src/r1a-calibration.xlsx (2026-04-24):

v_helm | I_helm | B | V_chip-avg
1 | 0.07 | 0 | 0.8637826607
2 | 0.163 | 0 | 0.8689834211
3 | 0.246 | 0.25 | 0.8750690893
4 | 0.289 | 0.35 | 0.8797499825
5 | 0.412 | 0.43 | 0.8856099091
6 | 0.494 | 0.52 | 0.89227215
7 | 0.575 | 0.6 | 0.8993290175
8 | 0.655 | 0.7 | 0.9054109388
9 | 0.734 | 0.8 | 0.9232046207
10 | 0.808 | 0.88 | 0.9279183
11 | 0.883 | 0.94 | 0.9322772
12 | 0.955 | 1.02 | 0.9361641579
13 | 1.024 | 1.1 | 0.9392484412
14 | 1.083 | 1.16 | 0.9413191068
15 | 1.148 | 1.24 | 0.9432587966

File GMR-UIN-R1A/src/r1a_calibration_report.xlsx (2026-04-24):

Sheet: Calibration Data
B_mT | V_chip-avg_V | V_smooth_V | dVdB_V_per_mT | B_fit_from_V
0.2 | 0.8916675932 | 0.8915986082 | 0.05063809056 | 0.1760753981
0.25 | 0.8939968136 | 0.8941305128 | 0.05350813947 | 0.2146436977
0.3 | 0.89693661 | 0.8969494222 | 0.06981630843 | 0.2633221965
0.34 | 0.9002061186 | 0.9001720944 | 0.0730416889 | 0.3174602214
0.39 | 0.903375 | 0.9033538591 | 0.06254885288 | 0.3699320135
0.44 | 0.9064098644 | 0.9064269797 | 0.08760672749 | 0.4201846914
0.47 | 0.9095239661 | 0.9095257792 | 0.08674909335 | 0.4717494167
0.53 | 0.9127308814 | 0.9127454179 | 0.06874178854 | 0.5248509915
0.57 | 0.9160230339 | 0.9158972533 | 0.08548521186 | 0.5793639644
0.61 | 0.9192232542 | 0.9195842349 | 0.09308653753 | 0.6323546818
0.65 | 0.9236218136 | 0.9233441763 | 0.08084784504 | 0.705188046
0.69 | 0.9262975424 | 0.9260520625 | 0.06739770841 | 0.7494939919
0.72 | 0.9275683729 | 0.9280672562 | 0.05881935835 | 0.7705369868
0.77 | 0.9306161695 | 0.930312077 | 0.05572400592 | 0.8210038021
0.81 | 0.9328024915 | 0.9328875201 | 0.05930184625 | 0.8572059259
0.85 | 0.9350366441 | 0.9350562247 | 0.0539737954 | 0.8942000492
0.89 | 0.9372359322 | 0.9372054237 | 0.05013772397 | 0.9306168717
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

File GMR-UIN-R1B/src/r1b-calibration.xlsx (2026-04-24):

v_helm | I_helm | B | V_chip-avg
3 | 0.267 | 0.21 | 0.8228303171
4 | 0.356 | 0.31 | 0.8456977634
5 | 0.449 | 0.42 | 0.870799573
6 | 0.531 | 0.49 | 0.8952328056
7 | 0.616 | 0.56 | 0.9141632813
8 | 0.699 | 0.62 | 0.9306032165
9 | 0.771 | 0.7 | 0.943401619
10 | 0.851 | 0.77 | 0.9558056316
11 | 0.925 | 0.83 | 0.965876069
12 | 0.983 | 0.9 | 0.9725501148
13 | 1.05 | 0.97 | 0.9793556769
14 | 1.106 | 1.12 | 0.982488975
15 | 1.173 | 1.2 | 0.9877541864

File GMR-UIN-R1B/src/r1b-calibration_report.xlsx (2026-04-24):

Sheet: Calibration Data
B_mT | V_chip-avg_V | V_smooth_V | dVdB_V_per_mT | B_fit_from_V
0.21 | 0.8228303171 | 0.8228420393 | 0.2844013423 | 0.1216782146
0.25 | 0.8343485902 | 0.834218093 | 0.2493129961 | 0.1849331224
0.31 | 0.8456977634 | 0.8460189216 | 0.2612708334 | 0.2472593846
0.35 | 0.8585422388 | 0.8581921644 | 0.2619754951 | 0.3177973983
0.42 | 0.870799573 | 0.871341891 | 0.3509991487 | 0.3851110086
0.45 | 0.8844715238 | 0.8839694558 | 0.3611934862 | 0.4601932696
0.49 | 0.8952328056 | 0.8952318438 | 0.3033727778 | 0.5192910075
0.52 | 0.904615593 | 0.9048238214 | 0.2824085069 | 0.5708184676
0.56 | 0.9141632813 | 0.9141295441 | 0.2261525195 | 0.6232515132
0.6 | 0.9229899344 | 0.9229160229 | 0.3302258862 | 0.6717248502
0.62 | 0.9306032165 | 0.9306261798 | 0.3132993389 | 0.713534716
0.67 | 0.9373730918 | 0.9372650836 | 0.1827748639 | 0.750712845
0.7 | 0.943401619 | 0.9436482717 | 0.2106462361 | 0.7838197118
0.73 | 0.9500509524 | 0.9499038578 | 0.1819809627 | 0.82033586
0.77 | 0.9558056316 | 0.9557677058 | 0.1620654281 | 0.8519388355
0.8 | 0.9608663 | 0.9609777262 | 0.1692803596 | 0.8797305115
0.83 | 0.965876069 | 0.9659245273 | 0.13573371 | 0.907242663
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

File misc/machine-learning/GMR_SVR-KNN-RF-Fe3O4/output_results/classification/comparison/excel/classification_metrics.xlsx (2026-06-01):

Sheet: Summary Metrics
Model | Accuracy | Precision (macro) | Recall (macro) | F1 (macro) | ROC-AUC (OvR) | CV Mean Acc | CV Std Acc
LogisticRegression | 0.981667 | 0.982971 | 0.981667 | 0.981636 | 0.999967 | 0.985 | 0.005055
SVM | 0.996667 | 0.9967 | 0.996667 | 0.996667 | 0.99997 | 0.996667 | 0.002582
KNN | 0.996667 | 0.9967 | 0.996667 | 0.996667 | 0.999 | 0.996667 | 0.002582
RandomForest | 0.998333 | 0.99835 | 0.998333 | 0.998333 | 0.99997 | 0.997667 | 0.001333

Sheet: Report_LogisticRegression
Class | Precision | Recall | F1-Score | Support
5 mg/mL | 1 | 0.91 | 0.95288 | 100
10 mg/mL | 0.917431 | 1 | 0.956938 | 100
20 mg/mL | 1 | 1 | 1 | 100
30 mg/mL | 1 | 1 | 1 | 100
40 mg/mL | 1 | 0.98 | 0.989899 | 100
50 mg/mL | 0.980392 | 1 | 0.990099 | 100

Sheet: Report_SVM
Class | Precision | Recall | F1-Score | Support
5 mg/mL | 0.990099 | 1 | 0.995025 | 100
10 mg/mL | 1 | 0.99 | 0.994975 | 100
20 mg/mL | 1 | 1 | 1 | 100
30 mg/mL | 1 | 1 | 1 | 100
40 mg/mL | 1 | 0.99 | 0.994975 | 100
50 mg/mL | 0.990099 | 1 | 0.995025 | 100
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

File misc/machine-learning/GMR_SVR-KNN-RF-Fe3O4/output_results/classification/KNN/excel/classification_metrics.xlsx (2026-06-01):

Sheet: Summary Metrics
Model | Accuracy | Precision (macro) | Recall (macro) | F1 (macro) | ROC-AUC (OvR) | CV Mean Acc | CV Std Acc
KNN | 0.996667 | 0.9967 | 0.996667 | 0.996667 | 0.999 | 0.996667 | 0.002582

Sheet: Report_KNN
Class | Precision | Recall | F1-Score | Support
5 mg/mL | 0.990099 | 1 | 0.995025 | 100
10 mg/mL | 1 | 0.99 | 0.994975 | 100
20 mg/mL | 1 | 1 | 1 | 100
30 mg/mL | 1 | 1 | 1 | 100
40 mg/mL | 1 | 0.99 | 0.994975 | 100
50 mg/mL | 0.990099 | 1 | 0.995025 | 100

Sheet: Cross_Validation
Model | Fold 1 | Fold 2 | Fold 3 | Fold 4 | Fold 5 | Mean | Std
KNN | 0.998333 | 0.991667 | 0.998333 | 0.998333 | 0.996667 | 0.996667 | 0.002582

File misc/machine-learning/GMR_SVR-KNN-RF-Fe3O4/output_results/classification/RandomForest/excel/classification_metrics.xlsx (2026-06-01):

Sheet: Summary Metrics
Model | Accuracy | Precision (macro) | Recall (macro) | F1 (macro) | ROC-AUC (OvR) | CV Mean Acc | CV Std Acc
RandomForest | 0.998333 | 0.99835 | 0.998333 | 0.998333 | 0.99997 | 0.997667 | 0.001333

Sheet: Report_RandomForest
Class | Precision | Recall | F1-Score | Support
5 mg/mL | 0.990099 | 1 | 0.995025 | 100
10 mg/mL | 1 | 0.99 | 0.994975 | 100
20 mg/mL | 1 | 1 | 1 | 100
30 mg/mL | 1 | 1 | 1 | 100
40 mg/mL | 1 | 1 | 1 | 100
50 mg/mL | 1 | 1 | 1 | 100

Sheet: Cross_Validation
Model | Fold 1 | Fold 2 | Fold 3 | Fold 4 | Fold 5 | Mean | Std
RandomForest | 0.998333 | 0.995 | 0.998333 | 0.998333 | 0.998333 | 0.997667 | 0.001333

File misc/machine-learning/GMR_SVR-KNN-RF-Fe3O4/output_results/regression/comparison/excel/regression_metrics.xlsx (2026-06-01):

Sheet: Summary Metrics
Model | MAE (mg/mL) | MSE | RMSE (mg/mL) | R² | MAPE (%) | CV Mean R² | CV Std R²
LinearRegression | 2.880839 | 13.614737 | 3.689815 | 0.947038 | 21.991713 | 0.944866 | 0.002995
SVR | 0.899695 | 1.619416 | 1.272563 | 0.9937 | 5.552278 | 0.993843 | 0.000383
KNN | 0.016667 | 0.083333 | 0.288675 | 0.999676 | 0.166667 | 0.999483 | 0.000145
RandomForest | 0.02653 | 0.078934 | 0.280952 | 0.999693 | 0.3543 | 0.999765 | 0.000125

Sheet: Residuals_LinearRegression
Actual (mg/mL) | Predicted (mg/mL) | Residual | Abs Residual
30 | 31.57691 | -1.57691 | 1.57691
20 | 24.25812 | -4.25812 | 4.25812
30 | 32.793455 | -2.793455 | 2.793455
5 | 5.957892 | -0.957892 | 0.957892
50 | 43.774893 | 6.225107 | 6.225107
20 | 25.474665 | -5.474665 | 5.474665
20 | 27.914262 | -7.914262 | 7.914262
40 | 41.296114 | -1.296114 | 1.296114
5 | 5.957892 | -0.957892 | 0.957892
50 | 43.774893 | 6.225107 | 6.225107
40 | 38.865216 | 1.134784 | 1.134784
5 | -3.800495 | 8.800495 | 8.800495
10 | 10.837085 | -0.837085 | 0.837085
30 | 32.793455 | -2.793455 | 2.793455
50 | 46.21449 | 3.78551 | 3.78551
10 | 9.62054 | 0.37946 | 0.37946
20 | 24.25812 | -4.25812 | 4.25812
5 | 5.957892 | -0.957892 | 0.957892
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

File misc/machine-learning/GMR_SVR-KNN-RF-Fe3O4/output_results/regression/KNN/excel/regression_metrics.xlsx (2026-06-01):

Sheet: Summary Metrics
Model | MAE (mg/mL) | MSE | RMSE (mg/mL) | R² | MAPE (%) | CV Mean R² | CV Std R²
KNN | 0.016667 | 0.083333 | 0.288675 | 0.999676 | 0.166667 | 0.999483 | 0.000145

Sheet: Residuals_KNN
Actual (mg/mL) | Predicted (mg/mL) | Residual | Abs Residual
30 | 30 | 0 | 0
20 | 20 | 0 | 0
30 | 30 | 0 | 0
5 | 5 | 0 | 0
50 | 50 | 0 | 0
20 | 20 | 0 | 0
20 | 20 | 0 | 0
40 | 40 | 0 | 0
5 | 5 | 0 | 0
50 | 50 | 0 | 0
40 | 40 | 0 | 0
5 | 5 | 0 | 0
10 | 10 | 0 | 0
30 | 30 | 0 | 0
50 | 50 | 0 | 0
10 | 10 | 0 | 0
20 | 20 | 0 | 0
5 | 5 | 0 | 0
50 | 50 | 0 | 0
50 | 50 | 0 | 0
5 | 5 | 0 | 0
5 | 5 | 0 | 0
10 | 10 | 0 | 0
40 | 40 | 0 | 0
20 | 20 | 0 | 0
50 | 50 | 0 | 0
50 | 50 | 0 | 0
20 | 20 | 0 | 0
5 | 5 | 0 | 0
20 | 20 | 0 | 0
20 | 20 | 0 | 0
30 | 30 | 0 | 0
10 | 10 | 0 | 0
50 | 50 | 0 | 0
5 | 5 | 0 | 0
10 | 10 | 0 | 0
40 | 40 | 0 | 0
5 | 5 | 0 | 0
5 | 5 | 0 | 0
20 | 20 | 0 | 0
5 | 5 | 0 | 0
5 | 5 | 0 | 0
5 | 5 | 0 | 0
10 | 10 | 0 | 0
30 | 30 | 0 | 0
30 | 30 | 0 | 0
40 | 40 | 0 | 0
5 | 5 | 0 | 0
50 | 50 | 0 | 0
30 | 30 | 0 | 0
20 | 20 | 0 | 0
40 | 40 | 0 | 0
5 | 5 | 0 | 0
40 | 40 | 0 | 0
5 | 5 | 0 | 0
50 | 50 | 0 | 0
20 | 20 | 0 | 0
10 | 10 | 0 | 0
50 | 50 | 0 | 0
20 | 20 | 0 | 0
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

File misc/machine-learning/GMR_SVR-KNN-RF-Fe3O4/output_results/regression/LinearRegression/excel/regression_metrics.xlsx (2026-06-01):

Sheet: Summary Metrics
Model | MAE (mg/mL) | MSE | RMSE (mg/mL) | R² | MAPE (%) | CV Mean R² | CV Std R²
LinearRegression | 2.880839 | 13.614737 | 3.689815 | 0.947038 | 21.991713 | 0.944866 | 0.002995

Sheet: Residuals_LinearRegression
Actual (mg/mL) | Predicted (mg/mL) | Residual | Abs Residual
30 | 31.57691 | -1.57691 | 1.57691
20 | 24.25812 | -4.25812 | 4.25812
30 | 32.793455 | -2.793455 | 2.793455
5 | 5.957892 | -0.957892 | 0.957892
50 | 43.774893 | 6.225107 | 6.225107
20 | 25.474665 | -5.474665 | 5.474665
20 | 27.914262 | -7.914262 | 7.914262
40 | 41.296114 | -1.296114 | 1.296114
5 | 5.957892 | -0.957892 | 0.957892
50 | 43.774893 | 6.225107 | 6.225107
40 | 38.865216 | 1.134784 | 1.134784
5 | -3.800495 | 8.800495 | 8.800495
10 | 10.837085 | -0.837085 | 0.837085
30 | 32.793455 | -2.793455 | 2.793455
50 | 46.21449 | 3.78551 | 3.78551
10 | 9.62054 | 0.37946 | 0.37946
20 | 24.25812 | -4.25812 | 4.25812
5 | 5.957892 | -0.957892 | 0.957892
50 | 46.21449 | 3.78551 | 3.78551
50 | 44.991439 | 5.008561 | 5.008561
5 | -3.800495 | 8.800495 | 8.800495
5 | 7.174437 | -2.174437 | 2.174437
10 | 9.62054 | 0.37946 | 0.37946
40 | 41.296114 | -1.296114 | 1.296114
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

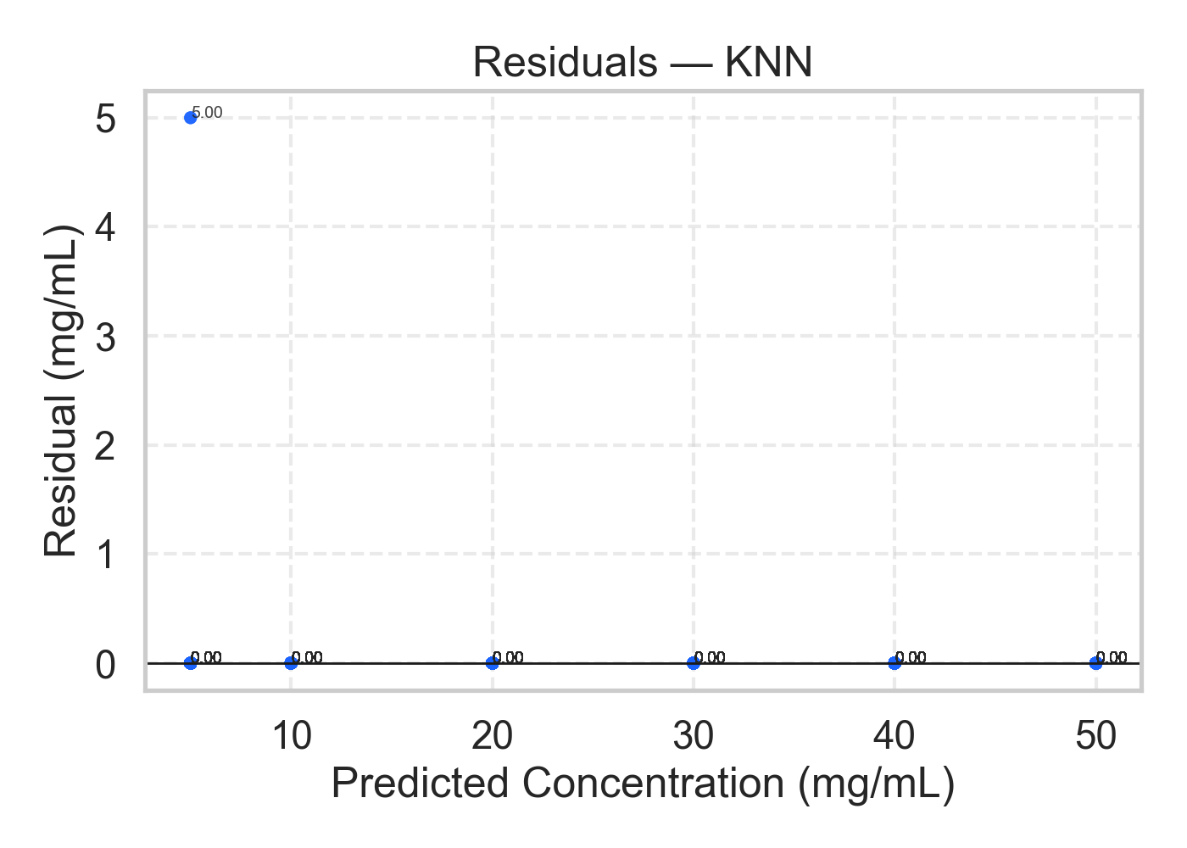
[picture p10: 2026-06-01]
misc/machine-learning/GMR_SVR-KNN-RF-Fe3O4/output_results/regression/KNN/plots/residuals.png

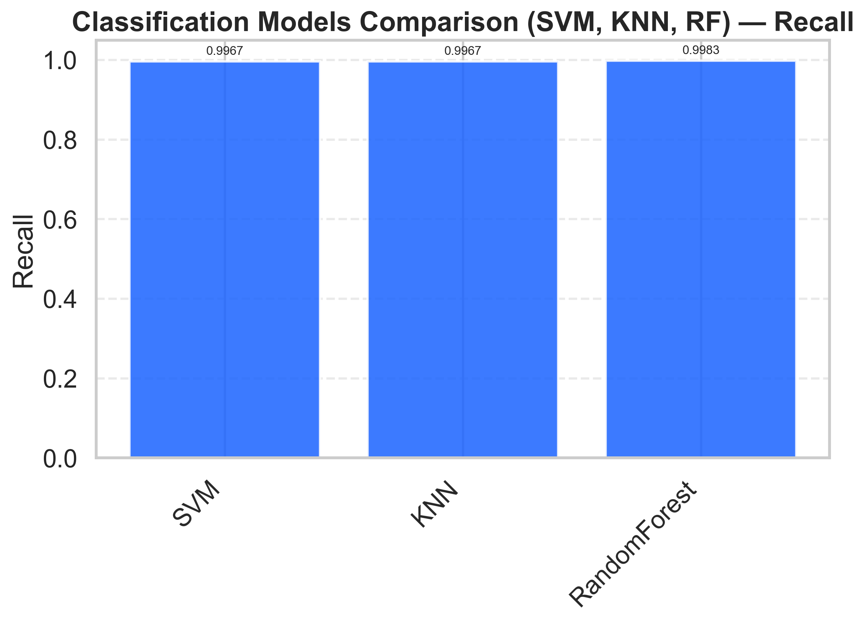
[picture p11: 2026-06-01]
misc/machine-learning/GMR_SVR-KNN-RF-Fe3O4/output_results/classification/comparison/plots/multiplots/3_models/multiplot_3_models_recall.png

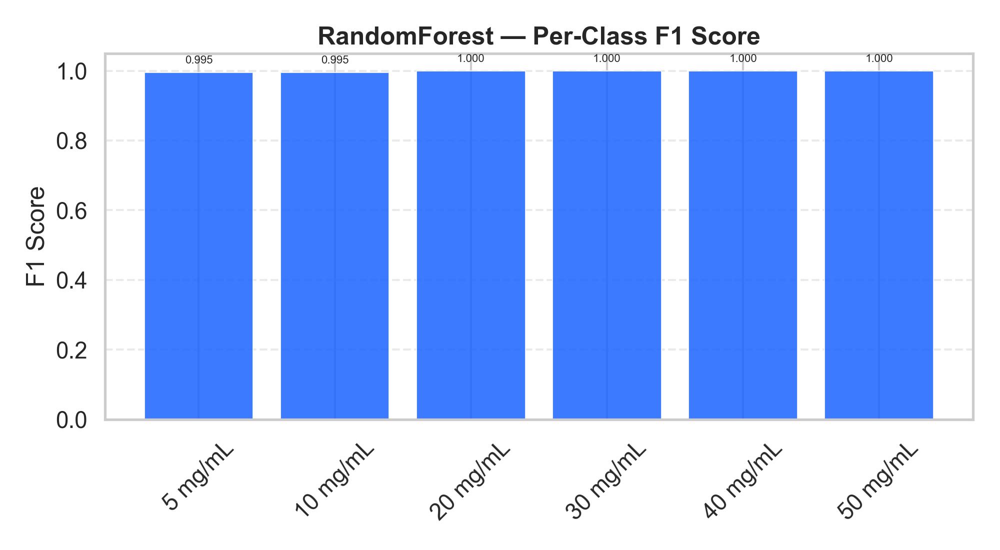
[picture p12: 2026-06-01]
misc/machine-learning/GMR_SVR-KNN-RF-Fe3O4/output_results/classification/RandomForest/plots/f1_score.png

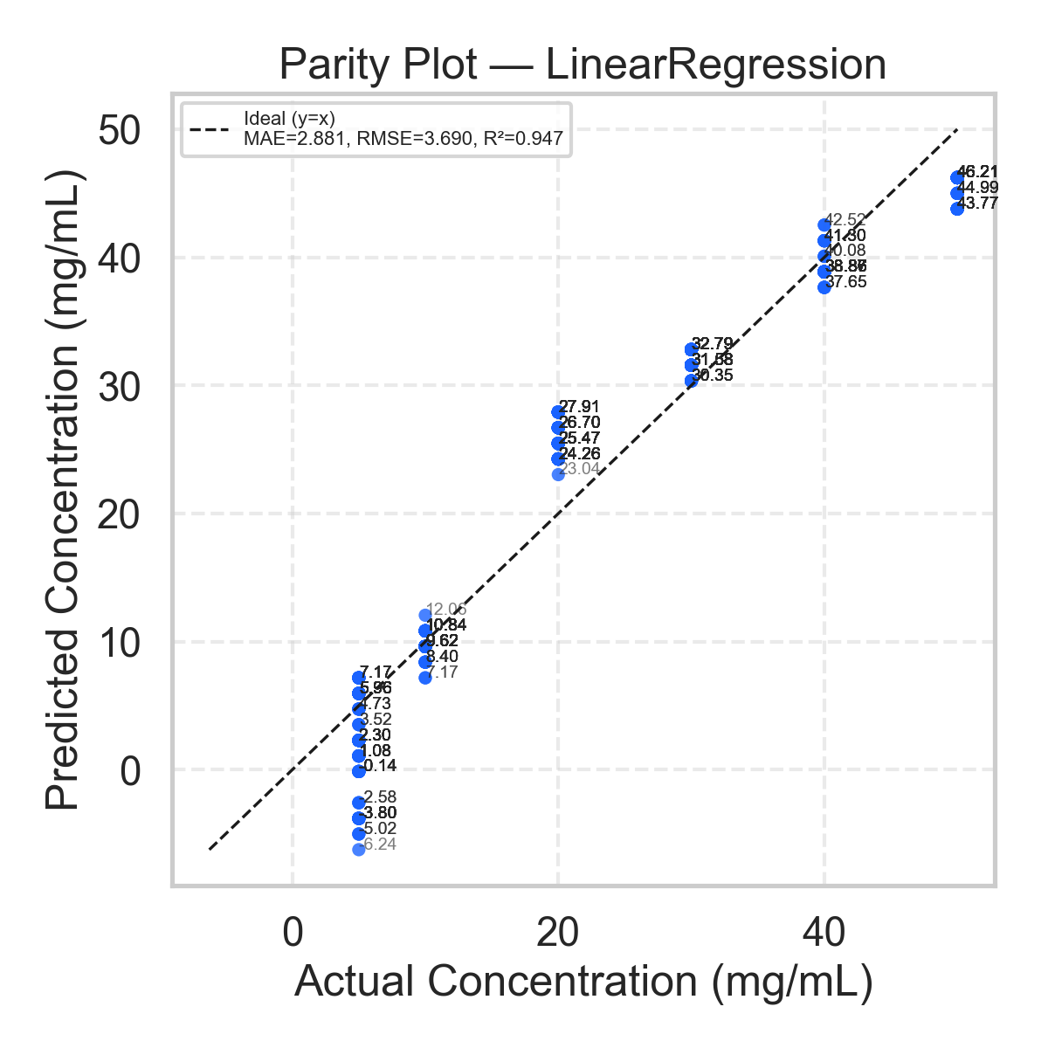
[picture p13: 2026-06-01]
misc/machine-learning/GMR_SVR-KNN-RF-Fe3O4/output_results/regression/LinearRegression/plots/parity.png

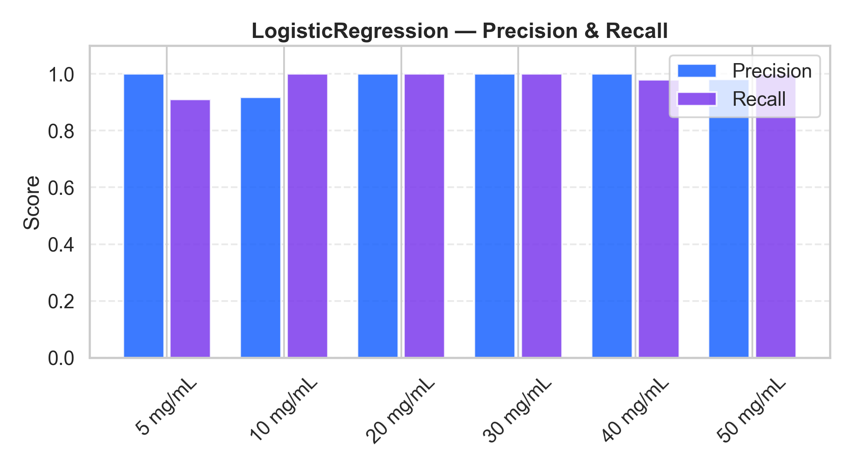
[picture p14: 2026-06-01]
misc/machine-learning/GMR_SVR-KNN-RF-Fe3O4/output_results/classification/LogisticRegression/plots/precision_recall.png

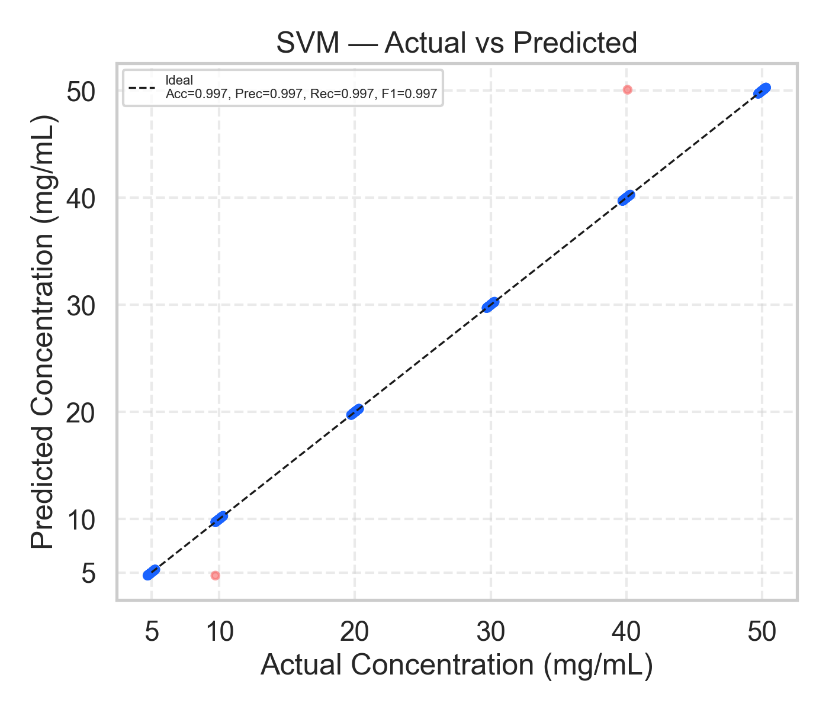
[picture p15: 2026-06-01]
misc/machine-learning/GMR_SVR-KNN-RF-Fe3O4/output_results/classification/SVM/plots/actual_vs_predicted.png

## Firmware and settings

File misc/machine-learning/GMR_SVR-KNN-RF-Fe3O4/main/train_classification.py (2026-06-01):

"""
GMR Fe3O4 Sensor - Classification Model Training
Models: SVC, KNN, Random Forest
Input: Delta-B (mT) from processed sheet, all iterations
Target: Concentration class (5, 10, 20, 30, 40, 50 mg/mL)
"""

import os
import json
import warnings
import numpy as np
import pandas as pd
import matplotlib
matplotlib.use("Agg")
import matplotlib.pyplot as plt
import matplotlib.gridspec as gridspec
import seaborn as sns
import joblib

from sklearn.pipeline import Pipeline
from sklearn.linear_model import LogisticRegression
from sklearn.svm import SVC
from sklearn.neighbors import KNeighborsClassifier
from sklearn.ensemble import RandomForestClassifier
from sklearn.model_selection import train_test_split, StratifiedKFold, cross_val_score
from sklearn.preprocessing import StandardScaler
from sklearn.metrics import (
    accuracy_score,
    precision_score,
    recall_score,
    f1_score,
    confusion_matrix,
    classification_report,
    roc_auc_score,
)
from openpyxl import Workbook
from openpyxl.styles import Font, PatternFill, Alignment, Border, Side
from openpyxl.utils import get_column_letter

warnings.filterwarnings("ignore")
sns.set_theme(style="whitegrid", context="talk")

# ─── CONFIG ──────────────────────────────────────────────────────────────────
_HERE = os.path.dirname(os.path.abspath(__file__))
REPO_ROOT = os.path.dirname(_HERE)

DATA_PATH = os.path.join(REPO_ROOT, "090526_fe3o4-data-gmr.xlsx")
SHEET_NAME = "Data_Acquisition_Processed"

BASE_OUT_DIR = os.path.join(REPO_ROOT, "output_results", "classification")
MODEL_DIR = os.path.join(REPO_ROOT, "models", "classification")

os.makedirs(MODEL_DIR, exist_ok=True)

RANDOM_STATE = 42
TEST_SIZE = 0.2
CV_FOLDS = 5

CONCENTRATIONS = [5, 10, 20, 30, 40, 50]
CLASS_NAMES = [f"{c} mg/mL" for c in CONCENTRATIONS]

COL_GROUPS = {
    5:  [1, 2, 3, 4, 5],
    10: [6, 7, 8, 9, 10],
    20: [11, 12, 13, 14, 15],
    30: [16, 17, 18, 19, 20],
    40: [21, 22, 23, 24, 25],
    50: [26, 27, 28, 29, 30],
}

COLORS = {
    "LogisticRegression": "#1A63FF",
    "SVM": "#1A63FF",
    "KNN": "#1A63FF",
    "RandomForest": "#1A63FF",
}

# ─── UTILITIES ───────────────────────────────────────────────────────────────
def ensure_dir(path):
    os.makedirs(path, exist_ok=True)


def dirs_for_classification_model(base_out, model_name):
    """output_results/classification/<Model>/{excel,json,plots}"""
    root = os.path.join(base_out, model_name)
    return {
        "root": root,
        "excel": os.path.join(root, "excel"),
        "json": os.path.join(root, "json"),
        "plots": os.path.join(root, "plots"),
    }


def dirs_classification_comparison(base_out):
    """output_results/classification/comparison/{excel,json,plots}"""
    root = os.path.join(base_out, "comparison")
    return {
        "root": root,
        "excel": os.path.join(root, "excel"),
        "json": os.path.join(root, "json"),
        "plots": os.path.join(root, "plots"),
    }

def style_header(cell, bg="1E40AF"):
    cell.font = Font(bold=True, color="FFFFFF", name="Arial", size=10)
    cell.fill = PatternFill("solid", start_color=bg)
    cell.alignment = Alignment(horizontal="center", vertical="center")
    cell.border = Border(
        left=Side(style="thin"),
        right=Side(style="thin"),
        top=Side(style="thin"),
        bottom=Side(style="thin"),
    )

def style_cell(cell):
    cell.font = Font(name="Arial", size=10)
    cell.alignment = Alignment(horizontal="center")
    cell.border = Border(
        left=Side(style="thin"),
        right=Side(style="thin"),
        top=Side(style="thin"),
        bottom=Side(style="thin"),
    )

def load_data(path, sheet):
    if not os.path.exists(path):
        raise FileNotFoundError(
            f"Data file not found: {path}\n"
            "Please place 090526_fe3o4-data-gmr.xlsx in the repository root."
        )
    raw = pd.read_excel(path, sheet_name=sheet, header=None)
    data = raw.iloc[2:].reset_index(drop=True)

    records = []
    for conc, cols in COL_GROUPS.items():
        for c in cols:
            col_data = pd.to_numeric(data.iloc[:, c], errors="coerce").dropna().values
            for val in col_data:
                records.append({"delta_B_mT": float(val), "concentration": int(conc)})

    return pd.DataFrame(records)

def build_models():
    return {
        "LogisticRegression": Pipeline(
            steps=[
                ("scaler", StandardScaler()),
                ("model", LogisticRegression(random_state=RANDOM_STATE, max_iter=1000)),
            ]
        ),
        "SVM": Pipeline(
            steps=[
                ("scaler", StandardScaler()),
                ("model", SVC(kernel="rbf", C=10, gamma="scale", probability=True, random_state=RANDOM_STATE)),
            ]
        ),
        "KNN": Pipeline(
            steps=[
                ("scaler", StandardScaler()),
                ("model", KNeighborsClassifier(n_neighbors=7, metric="euclidean")),
            ]
        ),
        "RandomForest": Pipeline(
            steps=[
                ("model", RandomForestClassifier(n_estimators=200, max_depth=None, random_state=RANDOM_STATE)),
            ]
        ),
    }

def _json_sanitize(obj):
    if isinstance(obj, dict):
        return {k: _json_sanitize(v) for k, v in obj.items()}
    if isinstance(obj, list):
        return [_json_sanitize(v) for v in obj]
    if isinstance(obj, (np.integer, np.floating)):
        return float(obj)
    return obj


def save_metrics_json(payload, output_path):
    ensure_dir(os.path.dirname(output_path))
    with open(output_path, "w", encoding="utf-8") as f:
        json.dump(_json_sanitize(payload), f, indent=4, ensure_ascii=False)

# ─── EXCEL OUTPUT ─────────────────────────────────────────────────────────────
def write_metrics_excel(all_metrics, cv_results, report_dicts, output_path):
    wb = Workbook()

    # Sheet 1: Summary Metrics
    ws = wb.active
    ws.title = "Summary Metrics"
    headers = [
        "Model",
        "Accuracy",
        "Precision (macro)",
        "Recall (macro)",
        "F1 (macro)",
        "ROC-AUC (OvR)",
        "CV Mean Acc",
        "CV Std Acc",
    ]
    for col, h in enumerate(headers, 1):
        style_header(ws.cell(1, col, h))

    for row, (name, m) in enumerate(all_metrics.items(), 2):
        vals = [
            name,
            m["accuracy"],
            m["precision"],
            m["recall"],
            m["f1"],
            m["roc_auc"],
            m["cv_mean"],
            m["cv_std"],
        ]
        for col, v in enumerate(vals, 1):
            c = ws.cell(row, col, round(v, 6) if isinstance(v, float) else v)
            style_cell(c)

    for col in range(1, len(headers) + 1):
        ws.column_dimensions[get_column_letter(col)].width = 20

    # Sheet 2: Per-Class Reports
    for model_name, report in report_dicts.items():
        ws2 = wb.create_sheet(f"Report_{model_name}")
        header_row = ["Class", "Precision", "Recall", "F1-Score", "Support"]
        for col, h in enumerate(header_row, 1):
            style_header(ws2.cell(1, col, h))

        for row, cls_name in enumerate(CLASS_NAMES, 2):
            m = report.get(cls_name, {})
            vals = [
                cls_name,
                m.get("precision", ""),
                m.get("recall", ""),
                m.get("f1-score", ""),
                m.get("support", ""),
            ]
            for col, v in enumerate(vals, 1):
                c = ws2.cell(row, col, round(v, 6) if isinstance(v, float) else v)
                style_cell(c)

        for col in range(1, 6):
            ws2.column_dimensions[get_column_letter(col)].width = 18

    # Sheet 3: CV Results
    ws3 = wb.create_sheet("Cross_Validation")
    style_header(ws3.cell(1, 1, "Model"))
    for fold in range(1, CV_FOLDS + 1):
        style_header(ws3.cell(1, fold + 1, f"Fold {fold}"))
    style_header(ws3.cell(1, CV_FOLDS + 2, "Mean"))
    style_header(ws3.cell(1, CV_FOLDS + 3, "Std"))

    for row, (name, scores) in enumerate(cv_results.items(), 2):
        ws3.cell(row, 1, name).font = Font(bold=True, name="Arial")
        for fold, s in enumerate(scores, 2):
            c = ws3.cell(row, fold, round(float(s), 6))
            style_cell(c)
        ws3.cell(row, CV_FOLDS + 2, round(float(np.mean(scores)), 6))
        ws3.cell(row, CV_FOLDS + 3, round(float(np.std(scores)), 6))

    for col in range(1, CV_FOLDS + 4):
        ws3.column_dimensions[get_column_letter(col)].width = 14

    wb.save(output_path)
    print(f"  [Excel] Saved -> {output_path}")

# ─── VISUALIZATION ────────────────────────────────────────────────────────────
def plot_classification_individual(model_name, metrics, cm, y_test, y_pred, report, plots_dir):
    ensure_dir(plots_dir)
    color = COLORS[model_name]

    # 1. Confusion matrix
    plt.figure(figsize=(8, 6.5))
    sns.heatmap(
        cm,
        annot=True,
        fmt="d",
        cmap=sns.light_palette(color, as_cmap=True),
        linewidths=0.5,
        annot_kws={"size": 8},
        xticklabels=CLASS_NAMES,
        yticklabels=CLASS_NAMES,
    )
    plt.title(f"{model_name} — Confusion Matrix", fontweight="bold")
    plt.xlabel("Predicted")
    plt.ylabel("Actual")
    plt.xticks(rotation=45)
    plt.tight_layout()
    plt.savefig(os.path.join(plots_dir, "confusion_matrix.png"), dpi=200)
    plt.close()

    # 2. Per-class F1
    plt.figure(figsize=(10, 5.5))
    f1s = [report[c]["f1-score"] for c in CLASS_NAMES]
    bars = plt.bar(CLASS_NAMES, f1s, color=color, alpha=0.85, edgecolor="white", linewidth=0.7)
    plt.title(f"{model_name} — Per-Class F1 Score", fontweight="bold")
    plt.ylim(0, 1.05)
    plt.ylabel("F1 Score")
    plt.grid(True, axis="y", ls="--", alpha=0.4)
    for bar, v in zip(bars, f1s):
        plt.text(
            bar.get_x() + bar.get_width() / 2,
            bar.get_height() + 0.02,
            f"{v:.3f}",
            ha="center",
            va="bottom",
            fontsize=8,
        )
    plt.xticks(rotation=45)
    plt.tight_layout()
    plt.savefig(os.path.join(plots_dir, "f1_score.png"), dpi=200)
    plt.close()

    # 3. Precision & Recall per class
    plt.figure(figsize=(10, 5.5))
    prec = [report[c]["precision"] for c in CLASS_NAMES]
    rec = [report[c]["recall"] for c in CLASS_NAMES]
    x = np.arange(len(CLASS_NAMES))
    plt.bar(x - 0.2, prec, 0.35, label="Precision", color=color, alpha=0.85, edgecolor="white")
    plt.bar(x + 0.2, rec, 0.35, label="Recall", color="#7C3AED", alpha=0.85, edgecolor="white")
    plt.title(f"{model_name} — Precision & Recall", fontweight="bold")
    plt.xticks(x, CLASS_NAMES, rotation=45)
    plt.ylim(0, 1.1)
    plt.ylabel("Score")
    plt.legend()
    plt.grid(True, axis="y", ls="--", alpha=0.4)
    plt.tight_layout()
    plt.savefig(os.path.join(plots_dir, "precision_recall.png"), dpi=200)
    plt.close()

    # 4. Overall metrics summary
    plt.figure(figsize=(9, 5.5))
    metric_names = ["Accuracy", "Precision\n(macro)", "Recall\n(macro)", "F1\n(macro)", "ROC-AUC"]
    metric_vals = [metrics["accuracy"], metrics["precision"], metrics["recall"], metrics["f1"], metrics["roc_auc"]]
    bars2 = plt.bar(metric_names, metric_vals, color=color, alpha=0.85, edgecolor="white")
    plt.ylim(0, 1.15)
    plt.title(f"{model_name} — Overall Metrics", fontweight="bold")
    plt.ylabel("Score")
    plt.grid(True, axis="y", ls="--", alpha=0.4)
    for bar, v in zip(bars2, metric_vals):
        plt.text(
            bar.get_x() + bar.get_width() / 2,
            bar.get_height() + 0.02,
            f"{v:.4f}",
            ha="center",
            va="bottom",
            fontsize=8,
        )
    plt.tight_layout()
    plt.savefig(os.path.join(plots_dir, "overall_metrics.png"), dpi=200)
    plt.close()

    # 5. Actual vs Predicted
    plt.figure(figsize=(7, 6))
    rng = np.random.default_rng(RANDOM_STATE)
    jitter = rng.uniform(-0.3, 0.3, len(y_test))
    colors_pt = [color if p == a else "#F87171" for p, a in zip(y_pred, y_test)]
    plt.scatter(y_test + jitter, y_pred + jitter, c=colors_pt, alpha=0.65, s=20)
    plt.plot([5, 50], [5, 50], "k--", lw=1.2, label=f"Ideal\nAcc={metrics['accuracy']:.3f}, Prec={metrics['precision']:.3f}, Rec={metrics['recall']:.3f}, F1={metrics['f1']:.3f}")
    plt.xlabel("Actual Concentration (mg/mL)")
    plt.ylabel("Predicted Concentration (mg/mL)")
    plt.title(f"{model_name} — Actual vs Predicted")
    plt.xticks(CONCENTRATIONS)
    plt.yticks(CONCENTRATIONS)
    plt.legend(fontsize=8)
    plt.grid(True, ls="--", alpha=0.4)
    plt.tight_layout()
    plt.savefig(os.path.join(plots_dir, "actual_vs_predicted.png"), dpi=200)
    plt.close()

    # 6. Sample counts
    plt.figure(figsize=(10, 5.5))
    counts_actual = [np.sum(y_test == c) for c in CONCENTRATIONS]
    counts_pred = [np.sum(y_pred == c) for c in CONCENTRATIONS]
    xb = np.arange(len(CLASS_NAMES))
    plt.bar(xb - 0.2, counts_actual, 0.35, label="Actual", color="#64748B", alpha=0.85, edgecolor="white")
    plt.bar(xb + 0.2, counts_pred, 0.35, label="Predicted", color=color, alpha=0.85, edgecolor="white")
    plt.xticks(xb, CLASS_NAMES, rotation=45)
    plt.title(f"{model_name} — Sample Count: Actual vs Predicted", fontweight="bold")
    plt.ylabel("Count")
    plt.legend()
    plt.grid(True, axis="y", ls="--", alpha=0.4)
    plt.tight_layout()
    plt.savefig(os.path.join(plots_dir, "sample_count_comparison.png"), dpi=200)
    plt.close()

    print(f"  [Plots] Saved -> {plots_dir} (6 figures: confusion matrix, f1, precision/recall, metrics, actual vs predicted, sample counts)")

def plot_classification_comparison(all_metrics, cv_results, report_dicts, cm_dict, y_test, preds, output_dir):
    ensure_dir(output_dir)

    fig = plt.figure(figsize=(22, 14))
    fig.suptitle(
        "Classification Comparison — SVM vs KNN vs Random Forest\nGMR Fe₃O₄ Sensor (ΔB, mT)",
        fontsize=15,
        fontweight="bold",
        y=0.99,
    )
    gs = gridspec.GridSpec(3, 4, figure=fig, hspace=0.55, wspace=0.4)

    model_names = list(all_metrics.keys())
    color_map = [COLORS[n] for n in model_names]
    metric_keys = ["accuracy", "precision", "recall", "f1", "roc_auc"]
    metric_labels = ["Accuracy", "Precision", "Recall", "F1", "ROC-AUC"]

    # Row 0: Confusion Matrices
    for idx, (name, color) in enumerate(zip(model_names, color_map)):
        ax = fig.add_subplot(gs[0, idx])
        sns.heatmap(
            cm_dict[name],
            annot=True,
            fmt="d",
            cmap=sns.light_palette(color, as_cmap=True),
            ax=ax,
            xticklabels=CLASS_NAMES,
            yticklabels=CLASS_NAMES,
            linewidths=0.5,
            annot_kws={"size": 7},
        )
        ax.set_title(f"{name} — Confusion Matrix", fontweight="bold", fontsize=10)
        ax.set_xlabel("Predicted", fontsize=8)
        ax.set_ylabel("Actual", fontsize=8)
        ax.tick_params(axis="x", rotation=45, labelsize=7)
        ax.tick_params(axis="y", rotation=0, labelsize=7)

    # Row 1 left: Grouped metric comparison
    ax_bar = fig.add_subplot(gs[1, :3])
    x = np.arange(len(metric_labels))
    width = 0.2
    for i, (name, color) in enumerate(zip(model_names, color_map)):
        vals = [all_metrics[name][k] for k in metric_keys]
        bars = ax_bar.bar(x + (i - 1.5) * width, vals, width, label=name, color=color, alpha=0.85, edgecolor="white")
        for bar, v in zip(bars, vals):
            ax_bar.text(
                bar.get_x() + bar.get_width() / 2,
                bar.get_height() + max(vals) * 0.01,
                f"{v:.3f}",
                ha="center",
                va="bottom",
                fontsize=8,
            )
    ax_bar.set_xticks(x)
    ax_bar.set_xticklabels(metric_labels)
    ax_bar.set_ylim(0, 1.15)
    ax_bar.set_ylabel("Score")
    ax_bar.set_title("Overall Metrics Comparison", fontweight="bold")
    ax_bar.grid(True, axis="y", ls="--", alpha=0.4)
    ax_bar.legend()

    # Row 1 right: CV boxplot
    ax_cv = fig.add_subplot(gs[1, 3])
    cv_data = [cv_results[n] for n in model_names]
    bp = ax_cv.boxplot(cv_data, patch_artist=True, labels=model_names)
    for patch, color in zip(bp["boxes"], color_map):
        patch.set_facecolor(color)
        patch.set_alpha(0.7)
    ax_cv.set_title(f"{CV_FOLDS}-Fold CV Accuracy", fontweight="bold")
    ax_cv.set_ylabel("Accuracy")
    ax_cv.grid(True, axis="y", ls="--", alpha=0.4)

    # Row 2: Per-class F1 for each model
    for idx, (name, color) in enumerate(zip(model_names, color_map)):
        ax = fig.add_subplot(gs[2, idx])
        report = report_dicts[name]
        f1s = [report[c]["f1-score"] for c in CLASS_NAMES]
        bars = ax.bar(CLASS_NAMES, f1s, color=color, alpha=0.85, edgecolor="white")
        ax.set_ylim(0, 1.2)
        ax.set_ylabel("F1 Score", fontsize=8)
        ax.set_title(f"{name} — Per-Class F1", fontweight="bold", fontsize=10)
        ax.tick_params(axis="x", rotation=45, labelsize=7)
        ax.grid(True, axis="y", ls="--", alpha=0.4)
        for bar, v in zip(bars, f1s):
            ax.text(
                bar.get_x() + bar.get_width() / 2,
                bar.get_height() + 0.02,
                f"{v:.3f}",
                ha="center",
                va="bottom",
                fontsize=7,
            )

    fig.tight_layout(rect=[0, 0, 1, 0.96])
    out_path = os.path.join(output_dir, "classification_comparison_all_models.png")
    plt.savefig(out_path, dpi=200, bbox_inches="tight")
    plt.close()
    print(f"  [Plot] Saved -> {out_path}")

def plot_classification_metrics_comparison(all_metrics, output_dir):
    ensure_dir(output_dir)
    
    model_names = list(all_metrics.keys())
    color_map = [COLORS[n] for n in model_names]
    
    metrics = [
        ("accuracy", "Accuracy", "accuracy_comparison.png"),
        ("precision", "Precision (macro)", "precision_comparison.png"),
        ("recall", "Recall (macro)", "recall_comparison.png"),
        ("f1", "F1 Score (macro)", "f1_comparison.png"),
    ]
    
    for key, label, filename in metrics:
        plt.figure(figsize=(8, 6))
        vals = [all_metrics[name][key] for name in model_names]
        bars = plt.bar(model_names, vals, color=color_map, alpha=0.85, edgecolor="white")
        plt.title(f"Classification {label} Comparison — SVM vs KNN vs Random Forest", fontweight="bold")
        plt.ylabel(label)
        plt.ylim(0, 1.05)
        plt.grid(True, axis="y", ls="--", alpha=0.4)
        for bar, v in zip(bars, vals):
            plt.text(
                bar.get_x() + bar.get_width() / 2,
                bar.get_height() + 0.01,
                f"{v:.4f}",
                ha="center",
                va="bottom",
                fontsize=10,
            )
        plt.tight_layout()
        out_path = os.path.join(output_dir, filename)
        plt.savefig(out_path, dpi=200, bbox_inches="tight")
        plt.close()
        print(f"  [Plot] Saved -> {out_path}")


def plot_multi_metric_comparison_classification(all_metrics, model_names, color_map, output_dir, filename, title):
    metrics = ["accuracy", "precision", "recall", "f1", "roc_auc"]
    labels = ["Accuracy", "Precision", "Recall", "F1", "ROC-AUC"]
    fig, axes = plt.subplots(2, 3, figsize=(15, 10))
    axes = axes.flatten()
    for i, (metric, label) in enumerate(zip(metrics, labels)):
        ax = axes[i]
        vals = [all_metrics[name][metric] for name in model_names]
        bars = ax.bar(model_names, vals, color=color_map[:len(model_names)], alpha=0.85, edgecolor="white")
        ax.set_title(f"{label} Comparison", fontweight="bold")
        ax.set_ylabel(label)
        ax.grid(True, axis="y", ls="--", alpha=0.4)
        for bar, v in zip(bars, vals):
            ax.text(bar.get_x() + bar.get_width()/2, bar.get_height() + max(vals)*0.01, f"{v:.3f}", ha="center", va="bottom", fontsize=8)
        ax.set_xticklabels(model_names, rotation=45, ha="right")
    # Hide the last subplot if 5 metrics
    axes[5].set_visible(False)
    plt.suptitle(title, fontsize=16, fontweight="bold")
    plt.tight_layout()
    out_path = os.path.join(output_dir, filename)
    plt.savefig(out_path, dpi=300, bbox_inches="tight")
    plt.close()
    print(f"  [Multiplot] Saved -> {out_path}")


def plot_multi_metric_comparison_classification_separate(all_metrics, model_names, color_map, output_dir, prefix, title):
    metrics = ["accuracy", "precision", "recall", "f1", "roc_auc"]
    labels = ["Accuracy", "Precision", "Recall", "F1", "ROC-AUC"]
    for metric, label in zip(metrics, labels):
        plt.figure(figsize=(8, 6))
        vals = [all_metrics[name][metric] for name in model_names]
        bars = plt.bar(model_names, vals, color=color_map[:len(model_names)], alpha=0.85, edgecolor="white")
        plt.title(f"{title} — {label}", fontweight="bold")
        plt.ylabel(label)
        plt.ylim(0, 1.05)
        plt.grid(True, axis="y", ls="--", alpha=0.4)
        for bar, v in zip(bars, vals):
            plt.text(bar.get_x() + bar.get_width() / 2, bar.get_height() + 0.01, f"{v:.4f}", ha="center", va="bottom", fontsize=8)
        plt.xticks(rotation=45, ha="right")
        plt.tight_layout()
        out_path = os.path.join(output_dir, f"{prefix}_{metric}.png")
        plt.savefig(out_path, dpi=300, bbox_inches="tight")
        plt.close()
        print(f"  [Multiplot] Saved -> {out_path}")
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

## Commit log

2026-04-24 commit: main init
    [10v.xlsx, 11v.xlsx, 12v.xlsx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]
2026-06-01 feat: MQTT setup w/ team
    [classification_metrics.xlsx, dataset_RF_glucose_monohydrate.xlsx, dataset_RF_glucose_monohydrate_GOx.xlsx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]
